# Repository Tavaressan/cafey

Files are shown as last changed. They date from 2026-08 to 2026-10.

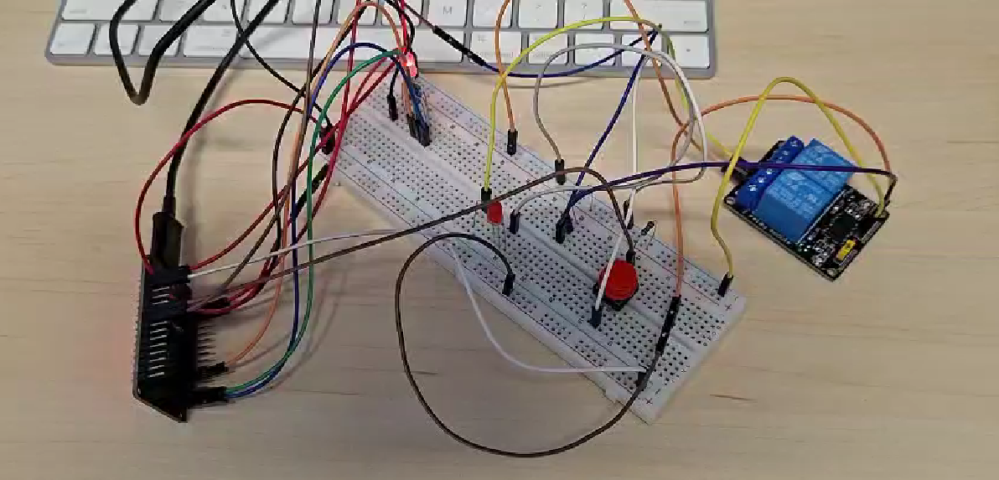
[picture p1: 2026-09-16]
docs/docs_artigo/imagens_artigo/screenshot_teste_bancada_prototipo_embarcado_cafey.png

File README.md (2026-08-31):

# Cafey — Cafeteira Conectada

Projeto Integrador do 6º semestre (Desenvolvimento de Software Multiplataforma, Fatec Itaquera).

Módulo IoT (Internet of Things — Internet das Coisas) externo, em formato de base de aço, que
transforma qualquer cafeteira de chave mecânica em aparelho conectado, sem modificação interna.
Um ESP32 aciona um relé que corta a fase da alimentação da cafeteira. Controle por app Kotlin
Multiplataforma (web/mobile/desktop), backend Kotlin + Spring Boot, PostgreSQL, MQTT (Message
Queuing Telemetry Transport) sobre AWS IoT Core.

## Estrutura

```
/
├── hardware/   KiCad — esquemático, PCB e bibliotecas do módulo eletrônico
├── firmware/   C++ / ESP-IDF — firmware do ESP32
├── backend/    Kotlin / Spring Boot — API e integração MQTT
├── apps/       Kotlin Multiplataforma — app web/mobile/desktop
└── docs/       Especificação e documentação acadêmica
```

## Abrindo o esquemático

Requer **KiCad 10.0.5** (ou outra versão 10.0.x) — a mesma versão maior usada para criar o
projeto. Abra `hardware/pi_dsm_26_2.kicad_pro`.

A biblioteca de símbolo de terceiros usada pelo ESP32 (`ESP32_30Pin`, DOIT ESP32 DevKit V1 de 30
pinos) está versionada em `hardware/libraries/esp32_30pin.kicad_sym` e registrada na tabela de
bibliotecas do projeto (`hardware/sym-lib-table`) com caminho relativo — não depende de nenhuma
biblioteca instalada fora do repositório.

## Aviso de segurança elétrica

O hardware envolve tensão de rede (127 V). A montagem exige validação por profissional de
elétrica antes do primeiro uso com carga real.

## Cronograma

Execução individual, oito semanas. Hardware e software avançam em paralelo, mas nunca no mesmo
dia: bancada e solda pedem bloco contínuo, código admite sessões curtas.

**Posição atual (31/08/2026):** Fase 1, esquemático elétrico validado. O gargalo do momento é a
compra dos componentes — ela bloqueia a bancada, o desenho mecânico e a validação elétrica ao
mesmo tempo.

### Fase 1 — Fundação (24/08 – 04/09)

| Estado | Entrega |
|---|---|
| ✅ | Especificação técnica v1.1 |
| ✅ | Seleção da cafeteira: Britânia CP30 Inox, 800 W, 127 V, chave KCD1-106 |
| ✅ | Decisões de hardware fechadas (alimentação, relé, LED, proteção, pinagem) |
| ✅ | Esquemático KiCad validado nó a nó contra a especificação |
| ✅ | Repositório e documentação de estado |
| ⬜ | Compra dos componentes |
| ⬜ | Conferência de bancada: serigrafia do DevKit, pinagem do módulo de relé, pernas do LED |
| ⬜ | Protótipo do relé em bancada acionado pelo ESP32 |
| ⬜ | Esqueleto do backend com autenticação |

### Fase 2 — Núcleo (07/09 – 25/09)

| Trilha | Entrega |
|---|---|
| Firmware | Estrutura de Active Objects sobre FreeRTOS; persistência em NVS (Non-Volatile Storage — armazenamento não volátil) |
| Firmware | MQTT sobre TLS (Transport Layer Security — segurança da camada de transporte) com certificado X.509; integração AWS IoT Core |
| Backend | API REST de dispositivos, comandos e agendamentos; consumo MQTT |
| Mobile | Operação básica: login, ligar, desligar, estado em tempo real |
| Estrutura | Desenho mecânico da chapa e solicitação de dobra à empresa |
| Artigo | Escrita incremental (ver trilha própria abaixo) |

### Fase 3 — Funcionalidade completa (28/09 – 09/10)

| Trilha | Entrega |
|---|---|
| Firmware | Agendamento local disparando por relógio sincronizado por NTP (Network Time Protocol — protocolo de tempo de rede) |
| Backend | Histórico de preparos, estatísticas, contador de descalcificação |
| Clientes | Web e desktop no nível essencial, reaproveitando composables |
| Estrutura | Montagem da base: fixação, aterramento, separação alta/baixa tensão |
| Segurança | Validação da montagem elétrica por profissional habilitado |

### Fase 4 — Fechamento (12/10 – 16/10)

| Trilha | Entrega |
|---|---|
| Testes | Ciclo completo com carga real; agendamento offline; queda de rede |
| Firmware | Fallback BLE (Bluetooth Low Energy — Bluetooth de baixa energia) e proxy BLE, se o cronograma permitir |
| Documentação | Documentação acadêmica e preparação para a banca |

## Estrutura física

A base é uma chapa de aço dobrada, produzida internamente na empresa. O caminho crítico passa
pela compra dos componentes: sem as dimensões reais das peças, o desenho não fecha.

| # | Atividade | Depende de |
|---|---|---|
| 1 | Levantar dimensões de ESP32, módulo de relé, HLK-PM01, tomada fêmea | Compras |
| 2 | Planificação da chapa: recortes de tomada, cabo, botão e LED | 1 |
| 3 | Definir separação física entre região de rede e região de baixa tensão | 2 |
| 4 | Resolver posicionamento da antena (janela plástica ou antena externa) | 2 |
| 5 | Prever fixação do terminal olhal de aterramento na chapa | 2 |
| 6 | Solicitar dobra à empresa | 2, 3, 4, 5 |
| 7 | Montagem: fiação de rede em bornes com tampa, fixação dos módulos | 6 |
| 8 | Validação elétrica por profissional habilitado | 7 |

O item 3 não é detalhe de acabamento: a especificação exige rede elétrica e eletrônica de baixa
tensão em lados opostos da caixa, sem cabos de alta e baixa tensão em paralelo. O item 4 existe
porque a estrutura metálica atenua Wi-Fi e BLE.

## Artigo — EnGeTec 2026

Submissão prevista para 20/09, dentro da Fase 2 — o período de maior carga técnica. Mitigação:
sessões fixas de escrita às terças, quintas e sábados, alimentadas pelas decisões já registradas
na especificação. O artigo descreve a proposta e resultados parciais; não depende do projeto
concluído.

**Confirmar a data no Teams** — a orientação da disciplina remete a ela, e a data acima vem da
especificação do projeto.

| Semana | Atividade |
|---|---|
| 31/08 – 06/09 | Cadastro no site do evento; levantamento bibliográfico |
| 31/08 – 06/09 | Definir recorte do artigo e estrutura das seções |
| 07/09 – 13/09 | Fundamentação teórica e método |
| 14/09 – 20/09 | Resultados parciais, conclusão, revisão de formatação |
| 20/09 | Submissão |
| a definir | Apresentação no evento (requisito para o certificado e para os anais) |

**Requisitos de submissão:**

- Template oficial do EnGeTec, sem qualquer alteração de formatação
- Mínimo de 10 artigos relacionados; referências em livros
- Não usar sites ou blogs como referência
- Título, resumo e palavras-chave em português, inglês e espanhol
- Resumo com no máximo 180 palavras
- Norma única em todo o texto: ABNT ou APA
- E-mail do professor orientador por último na lista de autores
- Declaração de uso (ou não uso) de ferramentas de IA ao final

## Marcos de aceitação

| Data | Critério |
|---|---|
| 04/09 | Relé aciona a carga por comando do ESP32; backend autentica ponta a ponta |
| 20/09 | Artigo submetido ao EnGeTec |
| 25/09 | Comando emitido no mobile chega à base via AWS IoT |
| 02/10 | Montagem elétrica validada por profissional |
| 09/10 | Agendamento dispara offline; histórico exibindo eventos reais |
| 16/10 | Projeto pronto para a banca |

## Ordem de cortes

Se o cronograma apertar, corta-se nesta ordem:

1. Fallback BLE e proxy BLE
2. Gráficos de estatística (mantendo o histórico em lista)
3. Compartilhamento de dispositivo com convidado
4. Cliente desktop
5. Recuperação de senha

**Nunca cortar:** agendamento offline, botão físico, aterramento e isolamento elétrico.

Ver [`STATUS.md`](STATUS.md) para o estado atual do projeto.

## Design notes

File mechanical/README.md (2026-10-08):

# mechanical — módulo físico (pedestal)

Modelo paramétrico do pedestal de `docs/status-modulo-fisico.md`.

**Impressão 3D (atual, issue #116):** ver a seção
[Variante para impressão 3D (FDM)](#variante-para-impressão-3d-fdm-issue-116)
abaixo — `build_peca1_3d.py` / `build_peca2_3d.py` e os scripts `*_3d.py`. A
seção seguinte, sobre chapa dobrada, fica preservada como histórico de decisão
(o modelo em chapa não é mais o alvo de fabricação, mas os scripts continuam
funcionando e não foram removidos).

## Chapa dobrada (histórico — substituída pela variante 3D acima)

- **Peça 1** — peça dobrada (tampo + 4 saias + 4 abas de fundo + 4 abas de canto).
- **Peça 2** — fundo plano removível (tampa por baixo).
- **Montagem** — as duas peças na posição de projeto.
- **Arranjo** — montagem + divisória + volumes de referência dos componentes
  (caixas envolventes **estimadas**, em `params/componentes.csv`).

## Abordagem

Sólidos `Part` paramétricos, 100% por script headless, dirigidos pelo Spreadsheet
`params`. Sem o addon SheetMetal: a planificação é analítica
(`bend deduction = 2·setback − BA`), auditável e independente do unfolder frágil.
O SheetMetal fica reservado para quando o revisor da empresa exigir árvore
sheet-metal nativa ou unfold validado pela ferramenta dele.

Parâmetros de processo (`espessura`, `raio_dobra`, `fator_k`, `material`) são
**placeholders arbitrados** — é a planilha `params` que o revisor corrige, e a
geometria depende dela por expressão.

## Coordenadas

Face superior do tampo em `Z = 0`; a peça desce para `Z < 0`. `X` ao longo de
`pegada_x`, `Y` ao longo de `pegada_y`. `Y = 0` é a saia frontal (baixa tensão),
`Y = pegada_y` a traseira (rede). `X = 0` é a lateral esquerda. As duas peças
compartilham este sistema, então a Peça 2 entra na montagem sem deslocamento.

## Scripts

```
freecadcmd mechanical/scripts/build_peca1.py     # build/peca1.FCStd
freecadcmd mechanical/scripts/unfold_peca1.py    # tabela de dobras -> Spreadsheet 'planificacao'
freecadcmd mechanical/scripts/check_peca1.py     # validação Peça 1
freecadcmd mechanical/scripts/export_step.py     # build/peca1.step
freecadcmd mechanical/scripts/build_peca2.py     # build/peca2.FCStd + peca2.step
freecadcmd mechanical/scripts/check_peca2.py     # validação Peça 2 + coincidência de furos
freecadcmd mechanical/scripts/build_montagem.py  # build/montagem.FCStd + montagem.step
freecadcmd mechanical/scripts/check_montagem.py  # validação de conjunto (pilha de parafuso, cobertura, elevação)
freecadcmd mechanical/scripts/build_arranjo.py   # build/arranjo.FCStd + arranjo.step (divisória + volumes de referência)
freecadcmd mechanical/scripts/check_arranjo.py   # valida faixas, altura livre, separação rede/baixa
freecadcmd mechanical/scripts/flatten_peca1.py   # build/peca1_plano.FCStd (contorno planificado)
freecadcmd mechanical/scripts/export_dxf.py      # build/peca1_plano.dxf + peca2_plano.dxf
```

Ordem: `build_peca1` → `build_peca2` → `build_montagem` → `check_montagem` →
`build_arranjo` → `check_arranjo`;  `flatten_peca1` → `export_dxf`. `freecadcmd` = `/Applications/FreeCAD.app/Contents/Resources/bin/freecadcmd`
(FreeCAD 1.1.3).

`_build.py` reúne o Spreadsheet e as primitivas; `_env.py` reúne paths, fórmulas
(BA, setback, segmentos do blank, furos de porca-rebite) e as descrições
(`DESCRIPTIONS`). Cada objeto do FCStd carrega `Label` + `Label2` (campo
"Descrição"); os objetos `notas_fabricacao` e `notas_furos` reúnem o que não é
geometria. **[`FUROS.md`](FUROS.md)** — catálogo do propósito de cada furo e
abertura, espelhado no `notas_furos` de cada FCStd.

## Entregáveis (`build/`, fora do versionamento)

| Arquivo | Conteúdo |
|---|---|
| `peca1.FCStd` / `peca1.step` | Peça 1, sólido paramétrico |
| `peca2.FCStd` / `peca2.step` | Peça 2, fundo plano |
| `montagem.FCStd` / `montagem.step` | Conjunto (snapshot; `check_montagem.py` valida interferência = 0, pilha de parafuso, cobertura das abas, elevação) |
| `arranjo.FCStd` / `arranjo.step` | Montagem + divisória + 13 volumes de referência; `check_arranjo.py` valida faixas, altura livre, separação rede/baixa |
| `peca1_plano.FCStd` | Contorno planificado da Peça 1 |
| `peca1_plano.dxf` | **Contorno externo** da Peça 1 (365,4 × 315,4 mm) — sem aberturas |
| `peca2_plano.dxf` | Peça 2 **completa** (contorno 260 × 210 + 8 furos M3 + 2 furos de cantoneira) |

## Peça 2 — fundo (tampa por baixo)

- Chapa plana rente à face externa das saias (260 × 210), **parafusada na face
  inferior das abas de retorno da Peça 1**. Sai por baixo para manutenção — um
  fundo apoiado por dentro sobre as abas viradas para dentro ficaria preso
  (vão livre entre as abas 233,6 × 183,6 < fundo). Face superior coplanar com a
  face inferior das abas; protrai `espessura_fundo` abaixo da borda das saias.
  Os pés montam nela.
- 8 furos de passagem M3 gerados pelas **mesmas fórmulas** das porcas-rebite da
  Peça 1 (`_env.porca_rebite_holes`); o parafuso entra por baixo e rosqueia na
  porca-rebite da aba. `check_peca2.py` confirma a coincidência.
- 2 furos para as cantoneiras da divisória, na linha `y = espessura + faixa_baixa`
  (policarbonato/acrílico, altura plena, entre a faixa de rede e a de baixa tensão).

## Arranjo interno (`arranjo.FCStd`)

`build_arranjo.py` monta Peça 1 + Peça 2 + a divisória + um volume de referência
por componente, lido de **`params/componentes.csv`**. Cada volume é uma **caixa
envolvente estimada** — o usuário confirma os tamanhos editando o CSV e rodando
de novo. Cada objeto carrega `Label2` com a origem da estimativa (datasheet do
HLK-PM01, dimensão de mercado, dado do documento…).

Layout: faixa da rede (127 V) na traseira, divisória de 3 mm, faixa de baixa
tensão (5 V) na frente. HLK-PM01 e módulo de relé do lado da rede com os
terminais de baixa tensão voltados para a divisória; travessia única de 5 fios
(`travessia_fios`) por um rasgo de passa-fio na divisória. ESP32 com o eixo longo
frente-fundo, antena atrás da `janela_rf`.

`check_arranjo.py` valida: envelope vertical, componente dentro das paredes, sem
penetrar a chapa, separação de faixa (rede ≥ 10 mm da divisória), só a travessia
cruza o plano da divisória, ESP32 alinhado com a janela de RF, e reporta
interferências entre volumes.

**Achado do 1º passe (tamanhos estimados):** a divisória a "altura plena" e os
componentes altos (`borne_rede` ~34 mm) deixam pouca folga sob o tampo — a
divisória (40 mm) fica a **2,6 mm** do tampo. Altura interna útil ~43,8 mm.
Confirmar as alturas reais e decidir a folga da divisória.

## Planificação e DXF — limites

O `peca1_plano.dxf` é **só o contorno** (mais alívios e abas de canto). As
aberturas por face **não entram**: a posição planificada de cada abertura depende
do fator K real da ferramenta da empresa (consultas 6 e 7 da lista de
verificação). O contorno serve para dimensionar a chapa bruta (~400 × 350 mm) e
como base para o revisor aplicar o unfold da ferramenta dele.

Aberturas, na referência da peça dobrada (do documento), para o desenho cotado:

| Face | Abertura | Posição |
|---|---|---|
| Frontal | Janela RF 40×28 | x=75, centro 22 mm abaixo do tampo |
| Frontal | LED Ø5 | x=150 |
| Frontal | Botão Ø12 | x=195 |
| Traseira | Prensa-cabo PG9 Ø15 | x=70 |
| Traseira | Tomada J1 45,5×23 | x=185 |
| Laterais | Rasgos 25×3 | 15 mm da borda inferior (4 na esq. + USB, 5 na dir.) |

## Estado / limitações

- **Sem raios de dobra** nos sólidos (arestas vivas). Cosméticos para o STEP; a
  linha neutra real está na planificação analítica.
- `usb_w`, `usb_h`: placeholders — medir o flange do conector (item 16).
- `espessura_fundo`: arbitrado; confirmar a chapa.
- Furos de canto e das cantoneiras em posições provisórias.
- Parafusos do fundo: cabeça panela (saliente ~2 mm no vão de ar). Sem escareado
  — chapa de 1,2 mm é fina para escarear M3; confirmar com a empresa se quiser flush.
- `montagem.FCStd` é snapshot (cópia de forma), não assembly vivo.

## Notas de fabricação (chapa)

- **Ordem de dobra:** abas do fundo primeiro, com a chapa plana; saias depois. A
  viradeira não alcança o interior de uma caixa de 45 × 260 mm.
- Alívio de canto de `raio_dobra + espessura` (~2,4 mm) no encontro das dobras.
- Porta-fusível em linha preso por abraçadeira — nenhum furo em chapa.
- Alumínio em inox forma par galvânico; parafuso/rebite de inox (consulta 9).

---

## Variante para impressão 3D (FDM) — issue #116

Reformulação da mecânica para impressão 3D no lugar de chapa dobrada. Mesma
pegada (260 × 210 mm), mesma **cavidade útil** (40,2 mm) e mesmo arranjo
interno (`params/componentes_3d.csv`). A **altura externa cresceu de 45 para
53 mm**: os 8 mm extras (`reforco_delta`) são uma banda de nervura sob o
tampo — o subconjunto interno (piso + componentes de `apoio=fundo` + divisória)
desceu junto, translação rígida, sem novo arranjo. O que muda:

- **Peça 1 vira um sólido único** (tampo + 4 paredes + flange de fixação
  contínua) em vez de 8 dobras + 4 abas de canto — os 4 cantos já nascem
  fechados, sem fator K, sem linha neutra, sem planificação.
- **Parede 2,4 mm** (3 perímetros de bico 0,4 mm), contra 1,2 mm da chapa —
  mínimo prático para uma parede que é estrutura primária em FDM.
- **Reforço estrutural sob o tampo** (audit da carga de 3 kg): 4 colunas de
  canto tampo→fundo + nervura perimetral + nervura transversal na linha da
  divisória. Tudo paramétrico (`coluna_qtd`, `nervura_transversal`,
  `nervura_h`). Ver "Reforço estrutural" abaixo.
- **Fixação Peça 1 / Peça 2 por insert térmico rosqueado M3** (fundido a
  quente em 8 bosses da flange, `boss_d` = 9 mm, furo do insert `insert_furo`
  = 4,0 mm, profundidade `insert_prof` = 6 mm), no lugar da porca-rebite de
  chapa. O parafuso da Peça 2 continua entrando por baixo.
- **STL exportável** (`export_stl.py`), novo requisito da issue.
- Todas as aberturas do catálogo (`FUROS.md`) recriadas 1:1 na nova geometria.

### Scripts

```
freecadcmd mechanical/scripts/build_peca1_3d.py     # build/peca1_3d.FCStd
freecadcmd mechanical/scripts/check_peca1_3d.py     # validação Peça 1 (geometria, margens, flecha do tampo)
freecadcmd mechanical/scripts/export_step_3d.py     # build/peca1_3d.step
freecadcmd mechanical/scripts/build_peca2_3d.py     # build/peca2_3d.FCStd + peca2_3d.step
freecadcmd mechanical/scripts/check_peca2_3d.py     # validação Peça 2 + coincidência dos furos com os inserts
freecadcmd mechanical/scripts/check_montagem_3d.py  # validação de conjunto (sem build_montagem_3d.py: confere as duas Shapes direto)
freecadcmd mechanical/scripts/build_arranjo_3d.py   # build/arranjo_3d.FCStd + arranjo_3d.step
freecadcmd mechanical/scripts/check_arranjo_3d.py   # valida faixas, altura livre, separação rede/baixa, sem colisão com os bosses
freecadcmd mechanical/scripts/export_stl.py         # build/peca1_3d.stl + peca2_3d.stl (Peça 1 e Peça 2)
```

Ordem: `build_peca1_3d` → `build_peca2_3d` → `check_peca1_3d` → `check_peca2_3d`
→ `check_montagem_3d` → `build_arranjo_3d` → `check_arranjo_3d` →
`export_step_3d` / `export_stl`.

`_env3d.py` é o equivalente de `_env.py` para esta variante: paths de saída
(`peca1_3d.*`, `peca2_3d.*`, `arranjo_3d.*`), `DESCRIPTIONS`/notas de
fabricação, `insert_holes()` (posição dos 8 bosses/insertes, mesmo layout dos
antigos `porca_rebite_holes()`), `coluna_positions()` / `pe_positions()` /
`y_nervura_transversal()` (geometria do reforço) e `deflexao_tampo_mm(g,
com_reforco=)` — flecha de longo prazo do tampo (elástica × `fator_fluencia`),
placa ret. simpl. apoiada (Roark). `_build.py` (helpers `box`/`cyl`) é
reaproveitado sem mudança.

### Parâmetros (`params/parametros_3d.csv`)

Cópia de `parametros.csv` sem os campos de dobra (`raio_dobra`, `fator_k`,
`recuo_aba`, `alivio_canto`), com `espessura` renomeado para `parede` (2,4 mm)
e os novos parâmetros de fixação: `boss_d`, `insert_furo`, `insert_prof`,
`furo_passagem`. `aba_fundo` sobe de 12 para 14 mm (a flange também aloja o
boss do insert, Ø 9 mm). Adicionados no audit da carga de 3 kg: `altura_externa`
45→53, `reforco_delta`, `nervura_h`/`nervura_w`/`nervura_transversal`,
`coluna_qtd`/`coluna_lado`, `travessia_folga`, `pe_d`/`pe_inset`,
`carga_operacao` (3,0 kgf), `fator_fluencia` (4,0), `folga_comp_reforco`.

### Reforço estrutural sob o tampo (audit da carga de 3 kg)

O modelo inicial do #116 só validava a flecha **elástica** do tampo sob
2,9 kg e passava raspando (0,57 mm vs. limite `L/300` = 0,70 mm). O audit
apontou dois furos: (1) faltava a **fluência** — PETG sob carga contínua +
calor irradiado deforma 3–4× a flecha elástica ao longo de meses; (2) o
pedido é **3 kg**, não 2,9. Com `fator_fluencia = 4` e `carga_operacao = 3,0`,
o tampo **liso** dá flecha de longo prazo ≈ **2,4 mm** — estoura o limite.

Reforço adicionado, todo paramétrico em `parametros_3d.csv`:

| Elemento | Param | Função |
|---|---|---|
| 4 colunas de canto (tampo → plano do fundo) | `coluna_qtd` (4), `coluna_lado` (12) | Caminho de carga vertical direto aos pés; travam o corpo contra racking |
| Nervura perimetral sob o tampo | `nervura_h` (6), `nervura_w` (3) | Enrijece a borda do tampo e o topo das paredes |
| Nervura transversal (linha da divisória) | `nervura_transversal` (1) | Divide o vão do tampo em 2 painéis → vão efetivo 210 → **118 mm**, flecha ÷ ~10 |
| Assentos de pé coaxiais com as colunas | `pe_d` (15) na Peça 2 | Fecham o caminho tampo → coluna → fundo → pé → bancada |

Resultado (`check_peca1_3d.py`): flecha de longo prazo **com** reforço ≈
**0,24 mm** < `L/300` = 0,70 mm. A peça imprime de cabeça para baixo (tampo
na mesa) — nervuras e colunas crescem a partir do tampo, **sem suporte**.

`coluna_qtd = 0` e `nervura_transversal = 0` voltam ao modelo do #118 (nesse
caso rebaixar `altura_externa` de 53 para 45). **Estimativa analítica, não
FEA nem ensaio** — o ensaio de bancada com o protótipo impresso e a carga
real por semanas (fluência) é o que confirma.

### Massa e resistência mecânica — decisões e premissas

- **Material assumido: PETG** (`_env3d.MATERIAL_TXT`), não validado por
  ensaio — ver `docs/status-modulo-fisico.md` para a justificativa e a
  ressalva. Densidade usada apenas para uma estimativa de massa em **sólido
  cheio** (limite superior; o infill parcial do fatiador reduz a massa real).
- **Flecha do tampo sob carga de operação:** `_env3d.deflexao_tampo_mm(g,
  com_reforco=)` — flecha **de longo prazo** = elástica (placa ret. simpl.
  apoiada, Roark) × `fator_fluencia`. `check_peca1_3d.py` reporta o valor
  **sem** reforço (≈ 2,4 mm, referência do audit) e valida o valor **com**
  reforço (≈ 0,24 mm) contra `L/300` do menor vão. **Inferência de
  engenharia, não ensaio** — item 8/10 da lista de verificação.
- **Sem fillet nos cantos verticais** nesta primeira versão — decisão
  consciente (YAGNI): nenhum requisito de resistência levantado pela issue
  exige isso agora; fica como melhoria futura se o ensaio de bancada indicar
  necessidade.

### Arranjo interno (`arranjo_3d.FCStd`)

Mesmos 14 componentes de `componentes.csv`, mesma separação rede/baixa
tensão. Ajustes em `componentes_3d.csv`:
- Componentes de `apoio=fundo` em standoffs acima do topo dos bosses de
  insert (que ficam mais altos que a flange de 2,4 mm).
- Todo o subconjunto interno referenciado ao piso (`apoio` ∈ fundo /
  divisória / abraçadeira / livre / fios) **desceu 8 mm** (`reforco_delta`)
  com o crescimento de `altura_externa` 45→53 — abre a banda de nervura sob
  o tampo sem mexer nas folgas internas (standoff 6 mm, divisória→piso
  2,4 mm são as mesmas do #118).
- Divisória 2,4 mm mais estreita de cada lado (255,2 × 3 × 40) e agora com
  topo em `z=-10,6` — 2,2 mm abaixo da nervura transversal.

`check_arranjo_3d.py` confirma: zero interferência entre os 14 volumes, zero
penetração na peça impressa, **8,1 mm** de folga sob o tampo (a banda de
nervura); e `check_peca1_3d.py` valida que nenhuma nervura/coluna colide com
os volumes internos (folga mínima 2,1 mm ≥ `folga_comp_reforco`).

**Modelos visuais.** Para 11 dos 13 componentes, `build_arranjo_3d.py` coloca
um modelo STEP/IGES de `models/` (tabela `MODELS`) sobre o volume de referência
e oculta a caixa. O modelo é só representação: a validação continua sobre as
caixas, e o build imprime quanto cada modelo passa do seu volume. Origem,
licença e divergências modelo × peça real estão em
[`models/FONTES.md`](models/FONTES.md). O `models/esp32-devkit-v1.step` é
montado por `make_esp32_devkit_v1.py` a partir da biblioteca 3D do KiCad. O `freecadcmd` não lê as cores dos
modelos; para gerar o FCStd e o STEP coloridos, rode o mesmo script pela GUI
do FreeCAD sem janela:

```
QT_QPA_PLATFORM=offscreen FreeCAD mechanical/scripts/build_arranjo_3d.py
```

### Entregáveis (`build/`, fora do versionamento)

| Arquivo | Conteúdo |
|---|---|
| `peca1_3d.FCStd` / `.step` / `.stl` | Peça 1 impressa (sólido único) |
| `peca2_3d.FCStd` / `.step` / `.stl` | Peça 2, fundo plano impresso |
| `arranjo_3d.FCStd` / `.step` | Peça 1 + Peça 2 + divisória + 13 volumes de referência (11 ocultos sob modelos visuais; o STEP leva só os visíveis, sem as peças) |

### Estado / limitações

- `usb_w`, `usb_h`: placeholders — medir o flange do conector (item 16, doc).
- `boss_d`/`insert_furo`/`insert_prof`: valores nominais de insert térmico
  M3x5,7 comum no mercado (ex. Ruthex/Boyard) — confirmar contra o insert
  realmente comprado antes de imprimir o protótipo.
- Sem fillet nos cantos verticais (ver acima).
- **`fator_fluencia` (4,0) é arbitrado** — faixa típica de termoplástico
  carregado, mas o valor real do PETG impresso sob a temperatura da base da
  cafeteira só sai de um ensaio de fluência de semanas (item 8/10). Se o
  ensaio der pior, subir `nervura_h` ou `parede`.
- **Flange na base imprime como ponte** de `aba_fundo` (14 mm) para dentro,
  sem chanfro 45° — aceitável para PETG a 14 mm, mas confirmar no protótipo;
  chanfro fica como melhoria paramétrica se reprovar.
- `pe_d`/`pe_inset`: assento de pé é só um rebaixo de localização (1,2 mm) —
  o pé em si (EPDM/silicone adesivo, `pe_altura` 10 mm) é externo.
- `arranjo_3d.FCStd` é snapshot, não assembly vivo (mesma limitação da
  versão em chapa).

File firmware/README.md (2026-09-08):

# Firmware — ESP32 (ESP-IDF C++17)

Firmware do módulo IoT da cafeteira Cafey desenvolvido em **C++17** sobre o framework oficial **ESP-IDF** (com FreeRTOS).

Fatia atual: **I/O local, Driver do Relé (com proteção anti-glitch no boot) e módulo Wi-Fi (conexão, reconexão automática e provisionamento de credenciais — UC-04)**. Botão alterna o relé; LED RGB indica o estado.

## Pinagem Definida

| Sinal | GPIO | Configuração Elétrica | Observação |
|---|---|---|---|
| Relé (IN) | 26 | Gatilho de nível BAIXO — módulo HL-52S (LOW = ligado); R1 10 kΩ pull-up externo | O driver força nível ALTO antes de inicializar para impedir pulso espúrio no boot |
| Botão | 27 | R2 10 kΩ pull-up externo + C3 100 nF debounce RC | Solto = 1, pressionado = 0 (borda de descida = clique) |
| LED vermelho | 21 | R3 220 Ω (Cátodo comum) | Aceso = cafeteira desligada |
| LED verde | 22 | R4 100 Ω (Cátodo comum) | Aceso = cafeteira ligada |
| LED azul | 23 | R5 100 Ω (Cátodo comum) | Aceso durante o boot |

## Estrutura do Projeto

```
firmware/
├── CMakeLists.txt         # Configuração raiz CMake (C++17, IDF project)
├── partitions.csv         # Tabela de partições customizada (nvs, phy_init, factory, storage)
├── sdkconfig.defaults     # Configurações do ESP-IDF (C++, partições, FreeRTOS 1000Hz)
├── wokwi.toml             # Configuração do simulador Wokwi
├── diagram.json           # Esquemático de simulação Wokwi
├── main/
│   ├── CMakeLists.txt     # Registro do componente main e fontes C++
│   ├── main.cpp           # Ponto de entrada app_main (extern "C") e namespace cafey
│   ├── drivers/
│   │   ├── relay.hpp      # Header do driver de relé C++ com RAII e anti-glitch
│   │   └── relay.cpp      # Implementação do driver cafey::drivers::Relay
│   └── core/              # Estruturas e active objects centrais
│       ├── reconnect_policy.hpp/.cpp    # Backoff exponencial puro (cafey::core::ReconnectPolicy)
│       ├── wifi_credentials.hpp/.cpp    # Persistência NVS de SSID/senha (cafey::core::WifiCredentialsStore)
│       └── wifi_manager.hpp/.cpp        # Orquestração Wi-Fi STA via esp_wifi/esp_event (cafey::core::WifiManager)
└── test/
    ├── CMakeLists.txt          # Suíte de testes unitários nativos para host (C++17 / CTest)
    ├── mock_esp_gpio.hpp       # Mock da camada GPIO do ESP-IDF para testes sem hardware
    ├── mock_esp_nvs.hpp        # Mock da camada NVS do ESP-IDF para testes sem hardware
    ├── test_relay.cpp          # Testes unitários do driver do relé (TDD)
    ├── test_reconnect_policy.cpp    # Testes unitários do backoff de reconexão (TDD)
    └── test_wifi_credentials.cpp    # Testes unitários da persistência de credenciais (TDD)
```

## Driver do Relé (`cafey::drivers::Relay`)

- **Classe Orientada a Objetos**: RAII garantindo desligamento seguro no destrutor.
- **Proteção Anti-Glitch**: Força o pino em nível lógico `HIGH` (active-low OFF) antes e imediatamente após a configuração de saída do GPIO, atuando em conjunto com o resistor `R1` (10k pull-up) externo.
- **Métodos**: `init()`, `set(bool on)`, `turn_on()`, `turn_off()`, `toggle()`, `is_on()`, `is_initialized()`, `get_pin()`.
- **Semântica Move**: Proteção contra duplicação de posse do hardware físico via exclusão de cópia e suporte a movimentação (`move`).

## Módulo Wi-Fi (`cafey::core::WifiManager`) — UC-04

- **Conexão STA**: inicializa `esp_wifi` em modo estação sobre o event loop padrão do ESP-IDF (`esp_event`).
- **Reconexão automática**: ao receber `WIFI_EVENT_STA_DISCONNECTED`, agenda uma nova tentativa via `esp_timer` (sem bloquear a task do event loop) com backoff exponencial calculado por `ReconnectPolicy` (1 s → dobra a cada falha → teto de 60 s); o contador de tentativas e o atraso são resetados ao obter IP (`IP_EVENT_STA_GOT_IP`).
- **Provisionamento de credenciais**: `WifiManager::provision(ssid, password)` grava o SSID/senha via `WifiCredentialsStore` (namespace NVS `cafey_wifi`) e conecta imediatamente; no boot, se já houver credenciais gravadas, conecta direto — caso contrário, permanece em `WifiState::NOT_PROVISIONED` aguardando o app/BLE provisionar (a exposição via BLE é escopo de FW-17).
- `ReconnectPolicy` e `WifiCredentialsStore` são unidades puras/isoladas do hardware, com testes unitários de host (`test_reconnect_policy.cpp`, `test_wifi_credentials.cpp`); `WifiManager` em si integra diretamente com `esp_wifi`/`esp_event`/`esp_timer` e é validado pela build real do ESP-IDF (CI).

## Executar Testes Unitários Nativos (Host)

Os testes unitários (driver do relé, backoff de reconexão e persistência de credenciais Wi-Fi) podem ser compilados e executados em qualquer máquina de desenvolvimento (macOS / Linux) sem necessidade da toolchain física do ESP-IDF instalada:

```sh
cd firmware/test
mkdir -p build && cd build
cmake ..
make
ctest --output-on-failure
```

## Simulação no Wokwi (wokwi.com)

1. Abra o Wokwi para ESP32 ESP-IDF (<https://wokwi.com/projects/new/esp-idf-esp32>).
2. Adicione os fontes de `firmware/` (`main.cpp`, `drivers/relay.hpp`, `drivers/relay.cpp`).
3. Cole o conteúdo de `diagram.json` e `wokwi.toml`.
4. Clique em **Run**. O log serial reportará o boot com LED azul e ao clicar no botão `SW1`, o relé e o LED alternam o estado.

### Simulação headless via `wokwi-cli` (CI local / validação sem hardware)

```sh
curl -L https://wokwi.com/ci/install.sh | sh   # instala em ~/bin/wokwi-cli
export WOKWI_CLI_TOKEN=<seu-token>             # gerado em https://wokwi.com/dashboard/ci
cd firmware
. ~/.espressif/v6.1/esp-idf/export.sh && idf.py build   # gera build/cafey_firmware.elf
wokwi-cli --serial-log-file /tmp/serial.log .            # lê wokwi.toml automaticamente
```

**Gotcha crítico:** `diagram.json` precisa conectar explicitamente os pinos TX0/RX0 do ESP32 ao
part virtual `$serialMonitor`, senão o `wokwi-cli` conecta na API normalmente e a simulação roda
(inclusive o firmware de verdade), mas **nenhum byte de serial chega ao CLI** — nem o banner de
boot do ROM, que independe do firmware. É silencioso: sem erro, sem timeout diferenciado, só
`--serial-log-file` vazio. As duas conexões que resolvem:
```json
[ "esp:TX0", "$serialMonitor:RX", "", [] ],
[ "esp:RX0", "$serialMonitor:TX", "", [] ]
```
Diagramas antigos/copiados do editor web às vezes não têm essa conexão (o editor web injeta um
monitor serial implícito que o `wokwi-cli` headless não replica). Rode `wokwi-cli lint .` para
pegar problemas de fiação — mas o lint não detecta a ausência do `$serialMonitor` (não é erro de
fiação, é ausência de conexão opcional do ponto de vista do simulador).

## Compilação Local com ESP-IDF (≥ 5.x)

```sh
. $IDF_PATH/export.sh
idf.py set-target esp32
idf.py build
idf.py -p <porta> flash monitor
```

### Evitando "idf.py: command not found"

- **`. export.sh` não persiste entre comandos de shell separados.** Cada terminal/execução novos
  precisa dar `source` de novo — não é algo que se "instala" uma vez. Se for automatizar (script,
  CI local, agente), o `source` e o `idf.py` têm que estar na **mesma** invocação de shell:
  ```sh
  . "$HOME/.espressif/v6.1/esp-idf/export.sh" && idf.py build
  ```
- **Instalação incompleta é a causa mais comum.** O toolchain (compiladores, cmake, ninja) pode já
  estar baixado em `~/.espressif/<versão>/` sem o venv Python ter sido criado — nesse caso
  `export.sh` falha com `ESP-IDF Python virtual environment ... not found`. Reinstale com:
  ```sh
  bash ~/.espressif/<versão>/esp-idf/install.sh esp32
  ```
- **A build real (`idf.py build`) é a única que valida o firmware de verdade.** A suíte de host
  (seção acima) cobre lógica pura via mocks, mas não pega problemas específicos do ESP-IDF (headers
  ausentes, `REQUIRES` de componente faltando, mudança de struct entre versões) — só o CI (Docker
  `espressif/idf:v5.3`) ou uma instalação local do ESP-IDF pegam isso. Se o Docker também estiver
  indisponível localmente (`docker info` falhando), a build real via `idf.py` é o único jeito de
  validar antes do CI.
- **Divergência de versão local vs. CI é uma fonte real de falso-negativo/falso-positivo.** O CI
  fixa `espressif/idf:v5.3`; uma instalação local em outra versão (ex. v6.1) pode expor mudanças de
  API/struct que não existem no v5.3 (e vice-versa). Ao investigar um erro de build que só aparece
  local ou só no CI, confira a versão primeiro (`idf.py --version`) antes de assumir que é bug de
  código.

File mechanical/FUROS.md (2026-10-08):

# Catálogo de furos e aberturas — módulo físico

**Nota (issue #116 — impressão 3D):** este catálogo descreve a versão em
chapa dobrada (`build_peca1.py`/`build_peca2.py`, histórico). A versão atual,
impressa em FDM (`build_peca1_3d.py`/`build_peca2_3d.py`), recria **as mesmas
aberturas, nas mesmas coordenadas (x, y, z)** — só os nomes de objeto mudam
(`saia_*` → `parede_*`; `fix_*`/`pr_*` → `boss_*`/`insert_*`, que agora
resolvem a fixação Peça1/Peça2 por insert térmico em vez de porca-rebite; não
há mais furo de canto porque a peça impressa já nasce fechada nos 4 cantos).
Ver `_env3d.NOTAS_FUROS_P1`/`NOTAS_FUROS_P2` (texto embutido no FCStd) e a
seção "Variante para impressão 3D" de `mechanical/README.md` para o
detalhamento da fixação nova. As tabelas abaixo continuam válidas para as
posições x/y das aberturas de face e dos rasgos — só a peça de fixação dos
cantos deixou de existir.

Propósito de cada furo/abertura dos modelos. Coordenadas no sistema das peças
(face superior do tampo em `Z = 0`; `X` ao longo de `pegada_x`; `Y = 0` = saia
frontal / baixa tensão; `Y = pegada_y` = saia traseira / rede; `X = 0` = lateral
esquerda). Espelhado nos FCStd pelos objetos `notas_furos` e pelo campo
**Descrição** (`Label2`) de cada objeto.

Valores são dos parâmetros arbitrados atuais — o revisor da empresa ajusta na
planilha `params` e a geometria acompanha por expressão.

---

## Peça 1 — aberturas de face

Centro a 22 mm abaixo do tampo (`abertura_centro_z`).

| Objeto | Forma | Face | Centro (x, y, z) | Propósito |
|---|---|---|---|---|
| `janela_rf` | retângulo 40 × 28 | frontal | (75, 0, −22) | **Saída de rádio.** Deixa a antena Wi-Fi do ESP32 (encostada por dentro, ~5 mm, sem metal na frente) enxergar para fora. Não é acesso a componente. Dimensão cobre a antena PCB do DevKit V1 com margem. Valida no ensaio 11 (atenuação de Wi-Fi). |
| `furo_led` | Ø5 | frontal | (150, 0, −22) | **Sinalização.** Passagem do LED RGB de status, preso na parede pelo aro (M2) e ligado à placa auxiliar da faixa de baixa tensão por um rabicho de 4 fios (R, G, B, cátodo) de ~10 cm com conector — ver `docs/status-modulo-fisico.md`, "LED de status". Ø nominal — conferir contra o LED/porta-LED real (item 5). |
| `furo_botao` | Ø16 | frontal | (195, 0, −22) | **Comando.** Passagem do botão de painel metálico momentâneo NA de 16 mm (revisão 08/09/2026; era Ø12). Ø nominal — conferir contra o botão real (M1 da lista de compras). Ligado à placa auxiliar por rabicho de 2 fios com JST-XH — ver `docs/status-modulo-fisico.md`, "Botão". |
| `prensa_cabo` | Ø15 | traseira | (70, 210, −22) | **Entrada de energia do módulo** (rede 127 V vinda da parede). Recebe o prensa-cabo PG9 — alívio de tração normalizado que a inspeção elétrica procura. Escolhido em vez de passa-fio ou C14: menor recorte numa saia que já perdeu a tomada J1. Faixa de aperto 4–8 mm nominal vs cabo real (item 14). |
| `tomada_j1` | retângulo 45,5 × 23 | traseira | (185, 210, −22) | **Saída de energia.** Recorte do módulo de tomada 2P+T (NBR 14136) onde a **cafeteira** é plugada; o módulo comuta essa tomada pelo relé. Girado 90°: 45 mm de recorte numa saia de 45 mm não deixaria material; girado sobram ~10 mm acima e abaixo. Travamento das garras em chapa 1,2 mm a verificar (item 1). |
| `recorte_usb` | retângulo ~16 × 9 | lateral esq. | (0, 37,5, −22) | **Gravação / debug.** Passagem do conector USB de painel, ligado ao micro-USB do ESP32 por cabo de painel. Esse cabo desacopla a posição do conector da da placa — no DevKit V1 antena e micro-USB ficam em extremidades opostas, então sem ele "USB acessível" e "Wi-Fi decente" seriam exclusivos. Dimensão **placeholder** — medir o flange real (item 16; cabo M8 da lista de compras). Ligação e percurso: `docs/status-modulo-fisico.md`, "USB de painel". |

## Peça 1 — rasgos de ventilação

**Função térmica.** 25 × 3 mm, centro a 15 mm da borda inferior da saia
(`rasgo_altura`). Com os pés, impedem a caixa de virar forno selado e deixam o
fundo trocar calor com o vão de ar — a fonte de calor está em cima e o topo é
fechado, então não há efeito chaminé. **3 mm bloqueia dedo, não bloqueia arame
fino → bornes com tampa na faixa de rede são obrigatórios.**

| Objeto | Face | Centro y | Observação |
|---|---|---|---|
| `rasgo_e_1` | lateral esq. | 71,25 | |
| `rasgo_e_2` | lateral esq. | 105 | |
| `rasgo_e_3` | lateral esq. | 138,75 | |
| `rasgo_e_4` | lateral esq. | 172,5 | |
| `rasgo_d_0` | lateral dir. | 37,5 | posição que na esquerda é do `recorte_usb` |
| `rasgo_d_1..4` | lateral dir. | 71,25 / 105 / 138,75 / 172,5 | |

A esquerda tem 4 (o USB ocupa a 5ª posição da grade); a direita tem 5. A
assimetria é proposital — não corrigir.

## Peça 1 — furação

| Objeto (padrão) | Ø / eixo | Qtd | Propósito |
|---|---|---|---|
| `fix_<e\|d><f\|t>_<lo\|hi>` | Ø3,2 (M3) / eixo X | 8 (2 por canto) | **Montagem da caixa.** Prende a aba de canto (que sai da saia frontal/traseira) contra a face interna da lateral, fechando o corpo. Parafuso M3 inox (premissa) ou rebite (alternativa paramétrica) — alumínio em inox forma par galvânico e aqui derrame de café é rotina (item 9). Alturas a 1/3 e 2/3 da saia — provisórias. |
| `pr_<f\|t\|e\|d><a\|b>` | Ø~4,5 / eixo Z | 8 (2 por aba) | **Fixação do fundo, lado Peça 1.** Recebe a porca-rebite M3 nas abas de retorno, onde os parafusos da Peça 2 entram. Ø de furo da porca-rebite para chapa 1,2 mm: ~4,5 mm nominal — confirmar item 17. |

Centros `fix_*`: x ≈ 1,2 / 258,8 · y ≈ 11,2 / 198,8 · z ≈ −30,4 (lo) / −15,8 (hi).
Centros `pr_*`: gerados por `_env.porca_rebite_holes` — x ∈ {7,2 · 86,7 · 173,3 ·
252,8}, y ∈ {7,2 · 70 · 140 · 202,8}, z ≈ −44,4.

## Peça 1 — o que **não** tem furo

- **Tampo:** nenhuma abertura (regra de derrame).
- **Fusível:** porta-fusível 5×20 mm **em linha** (com rabicho), corpo fechado,
  preso por abraçadeira. Nenhum furo na parede — troca abrindo o fundo.
  Confirmado na revisão de 08/09/2026 (item E12 da lista de compras): **não**
  usar porta-fusível de painel. F1 = 10 A T, protege a carga.
- **Travessia de 5 fios** (+5 V/GND do HLK-PM01 + VCC/GND/IN do relé): rasgo com
  passa-fio na **divisória** de policarbonato, perpendicular a ela — não na
  chapa. A divisória não está modelada.
- `relief_*`: alívios de canto (entalhe no encontro das dobras), não furos.

---

## Peça 2 — fundo plano (tampa por baixo)

Chapa plana rente à face externa das saias (260 × 210), **parafusada na face
inferior das abas de retorno da Peça 1**. Sai por baixo para manutenção — um
fundo apoiado por dentro sobre as abas viradas para dentro ficaria preso (o vão
livre entre as bordas internas das abas é 233,6 × 183,6, menor que o fundo).
Face superior coplanar com a face inferior das abas (`Z = −altura_externa`);
protrai `espessura_fundo` (1,2 mm) abaixo da borda das saias. Os pés montam nela.

| Objeto (padrão) | Ø / eixo | Qtd | Propósito |
|---|---|---|---|
| `fundo_furo_1..8` | Ø3,2 (M3) / eixo Z | 8 | **Fixação do fundo, lado Peça 2.** Furo de **passagem**: o parafuso entra por baixo e rosqueia na porca-rebite `pr_*` da aba da Peça 1. Coincidem com os `pr_*` — mesmas fórmulas em `_env.porca_rebite_holes`, `check_peca2.py` confirma. Cabeça panela no vão de ar entre os pés. Abrir o fundo = trocar o fusível e acessar todo o interior. |
| `cant_furo_1..2` | Ø3,2 (M3) / eixo Z | 2 | **Separação elétrica.** Fixam as cantoneiras que seguram a divisória (policarbonato ou acrílico, altura plena) na linha `y = espessura + faixa_baixa` ≈ 85, entre a faixa de rede (127 V, traseira) e a de baixa tensão (5 V, frontal). Nenhum condutor de rede a menos de 10 mm da divisória — valida com o eletricista (marco 02/10). |

Centros `fundo_furo_*` = mesmos (x, y) dos `pr_*`. Centros `cant_furo_*`:
(65, 85,2) e (195, 85,2).

---

## Variante impressa (FDM) — fixação Peça 1 / Peça 2

Substitui `fix_*` (parafuso de canto — não existe mais, peça já nasce
fechada) e `pr_*`/`fundo_furo_*` (porca-rebite) da chapa. Mesmas 8 posições
(x, y) — geradas por `_env3d.insert_holes`, layout idêntico ao antigo
`_env.porca_rebite_holes`.

| Objeto (padrão) | Ø / eixo | Qtd | Propósito |
|---|---|---|---|
| `boss_<f\|t\|e\|d><a\|b>` | Ø9 (boss_d) / eixo Z | 8 | Reforço cilíndrico na flange, altura `insert_prof` (6 mm) — mais alto que a flange (2,4 mm) para caber o insert. Motivo do ajuste de z dos componentes `apoio=fundo` em `componentes_3d.csv` (sobem para standoff acima do boss). |
| `insert_<f\|t\|e\|d><a\|b>` | Ø4,0 (insert_furo) / eixo Z | 8 | Furo cego pela face inferior, profundidade 6 mm. Aloja o insert térmico M3×5,7 fundido a quente após a impressão. |
| `fundo_furo_1..8` (Peça 2) | Ø3,4 (furo_passagem) / eixo Z | 8 | Folga do parafuso M3 na Peça 2 — mesma lógica de montagem da chapa (parafuso entra por baixo, rosqueia no insert). |

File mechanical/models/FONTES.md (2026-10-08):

# Modelos visuais — origem, licença e divergências

Modelos usados por `scripts/build_arranjo_3d.py` (tabela `MODELS`) no lugar das
caixas de `params/componentes_3d.csv`. São **representação visual**: a validação
(`check_arranjo_3d.py`) continua sobre as caixas, que ficam ocultas no FCStd.

| Arquivo | Componente | Origem | Licença |
|---|---|---|---|
| `esp32-devkit-v1.step` | `esp32` | Gerado por `scripts/make_esp32_devkit_v1.py` com peças da biblioteca 3D do KiCad 10.0 (WROOM-32, 2× barra 1×15, micro-USB Molex 47346, 2× PTS810, SOT-223, QFN-28); placa, furos e fileiras pelo footprint `ESP32_30pin` de [syauqibilfaqih/ESP32-DevKit-V1-DOIT](https://github.com/syauqibilfaqih/ESP32-DevKit-V1-DOIT) @ `80365a4` (MIT) | Idem KiCad |
| `modulo-rele-v3.step` | `modulo_rele` | GrabCAD, `5v-relay-module-v3-0-1.snapshot.6.zip` | Termos do GrabCAD |
| `barramento-terra-lukma-6p.iges` | `terra_j3` | GrabCAD, `barra-de-bornes-terra-1.snapshot.6.zip` (`Barramento Terra LUKMA.iges`) | Termos do GrabCAD |
| `porta-fusivel-inline.step` | `porta_fusivel` | GrabCAD, `inline-fuse-holder-1.snapshot.2.zip` (autor no cabeçalho: jvalderrama) | Termos do GrabCAD |
| `tomada-tpa2-3-e3f.igs` | `tomada_j1_corpo` | GrabCAD, `tomada-2p-t-10-a-nbr-14136-referencia-tpa2-3-e3f-…-black-1.snapshot.2.zip` | Termos do GrabCAD |
| `placa-ilhada-60x40.step` | `placa_aux` | GrabCAD, `prototype-pcb-1.snapshot.1.zip` (`STEP/60mm x 40mm.step`) | Termos do GrabCAD |
| `PG9 Gland.step` | `prensa_cabo_corpo` | Baixado pela equipe como modelo do prensa-cabo PG9 (peça sem modelo na primeira busca); site de origem não anotado (cabeçalho: exportado do FreeCAD, 2023-01-13) | Desconhecida |
| `hlk-pmxx.step` | `hlk_pm01` | Biblioteca 3D do KiCad 10.0, `Converter_ACDC.3dshapes/Converter_ACDC_Hi-Link_HLK-PMxx.step` | [CC-BY-SA 4.0 com exceção para designs e arquivos gerados](https://gitlab.com/kicad/libraries/kicad-packages3D/-/blob/master/LICENSE.md) |
| `led-5mm-rgb.step` | `led_rgb` | Biblioteca 3D do KiCad 10.0, `LED_THT.3dshapes/LED_D5.0mm-4_RGB.step` | Idem KiCad |
| `adafruit-916-botao-metal-16mm.step` | `botao` | [adafruit/Adafruit_CAD_Parts](https://github.com/adafruit/Adafruit_CAD_Parts) @ `c128bce`, `916 metal button/916 Metal Button.step` | MIT |
| `adafruit-3258-microusb-painel.step` | `usb_painel` | Idem, `3258 USB Panel Mout Cable/3258 microUSB panel mount.step` | MIT |

Os nomes de `.zip` acima identificam o download original no GrabCAD; os zips
foram apagados em 08/10/2026 e só os arquivos usados ficaram aqui. Também
baixados e não usados: `tomada-eletrica-de-3-pinos…` (é um **plugue** macho,
não tomada), `Barramento de terra 12 Posições.STEP` (124 mm, não cabe na faixa
de rede), `bloque-de-terminales-2-rojo-1…` (borne de PCB de 2 vias, sem
componente definido) e `esp32-c3-mini-devkit-1…` (ESP32-C3, substituído pelo
DevKit V1 montado).

**Licença — antes de versionar.** O repositório é público. A
[central de ajuda do GrabCAD](https://help.grabcad.com/article/246-how-can-models-be-used-and-shared)
admite uso público não comercial com crédito e link ao autor, mas os
[Termos de Uso](https://grabcad.com/terms) concedem licença intransferível e não
sublicenciável, para uso próprio, interno e não comercial. Redistribuir os
arquivos (e o `arranjo_3d.step` gerado, que embute a geometria) num repositório
público não está claramente autorizado: pedir permissão aos autores ou manter
esses arquivos fora do git.

## Divergências modelo × peça do projeto

Os modelos são os mais próximos encontrados, não a peça comprada. Conferir
antes de usar o arranjo como referência dimensional:

- **`esp32`**: DevKit V1 montado — placa, furos, fileiras de pinos, WROOM-32 e
  micro-USB nas posições do footprint; botões EN/BOOT, AMS1117 e CP2102 em
  posição representativa; placa preta por escolha visual. Ocupa
  28,3 × 52,6 × 13,2 mm contra o volume de 29 × 52 × 13 (o micro-USB passa
  1,1 mm da borda). Para regerar: `QT_QPA_PLATFORM=offscreen FreeCAD
  mechanical/scripts/make_esp32_devkit_v1.py` (precisa do KiCad instalado).
- **`modulo_rele`**: o modelo tem **1 canal** (47 × 27 mm); o projeto usa o de
  2 canais LAFVIN (~50 × 39). Girado com a barra IN/5V/GND voltada para a
  divisória, passa 8 mm do volume em Y.
- **`terra_j3`**: barramento de terra de 6 posições (84,9 mm) contra um volume
  de 18 mm; a lista de compras pede borne DIN verde-amarelo em trilho (E14/E15).
  O IGES traz a barra como faces soltas e sem cor: o build lê com `Part.read` e
  pinta apoios de verde e barra/parafusos de latão.
- **`porta_fusivel`**: porta-fusível de **lâmina** (automotivo); a lista pede
  5×20 mm de vidro in-line (E12). Os rabichos de 138 mm são descartados no build.
- **`tomada_j1_corpo`**: moldura 45 × 25 mm, corpo ~44,2 × 21,2; o recorte
  `tomada_j1` é 45,5 × 23 — em X a moldura é **menor** que o recorte. IGES só de
  faces (sem sólido): no STEP reimportado vira um objeto por face.
- **`botao`**: Adafruit 916 é a versão **liga/desliga com anel de LED**; a lista
  (M1) pede momentâneo NA sem anel. Mesmo furo de 16 mm.
- **`usb_painel`**: corpo 12 × 9,8 mm contra o recorte `usb_w` × `usb_h` de
  16 × 9 (placeholder) — 0,8 mm mais alto que o recorte; flange com orelhas de
  parafuso de 25 mm que o recorte atual não prevê.
- **`prensa_cabo_corpo`**: o modelo prevê parede de 2,0 mm; com 2,4 mm a
  contraporca invade 0,4 mm a parede (só visual).
- **`hlk_pm01`**: pinos 4,9 mm abaixo do corpo; o volume de 15 mm não os incluía
  (passa 5 mm em Z). Eixo longo em X, com a saída DC voltada para a travessia.
- **`placa_aux`**: só a placa ilhada, sem C1/C2/C3/R1–R5 (o leiaute não
  existe ainda). O modelo de 60 × 40 é recortado no build para os 45 × 32 do
  volume; a altura de 26 mm do volume (definida pelo C1) não aparece. O STEP
  não traz cor: o build pinta fenolite e as ilhas de cobre.

Sem modelo (continuam caixa): `borne_rede` (a lista de compras troca os bornes
por conectores WAGO 221) e `travessia_fios`.

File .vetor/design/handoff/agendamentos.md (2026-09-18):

# Design Contract — Agendamentos

## Objetivo da experiência

Gerenciar horários automáticos de preparo, expressos como 'café pronto às' (não 'ligar às') — listar os existentes e criar um novo.

## Telas

Uma tela com lista de agendamentos + editor. No celular, lista e editor ficam empilhados na mesma página (desvio documentado no README — no design original eram duas pranchetas separadas); no desktop, ficam lado a lado.

## Hierarquia

1) Próximo agendamento ativo (destacado) no topo da lista; 2) demais agendamentos (ativo 'domingo', pausado); 3) nota informativa sobre funcionamento offline; 4) editor de novo agendamento (hora, dias, timeout, salvar/cancelar).

## Layout

Celular (<768): lista e editor empilhados verticalmente, editor com barra de cabeçalho própria (Cancelar/Novo agendamento/Salvar). Tablet (768–1023): mesmo empilhamento (wide--late só abre no desktop). Desktop (≥1024): lista e editor lado a lado (grid 1fr/1fr), sem a barra de cabeçalho do editor (usa botões Salvar/Cancelar no rodapé em vez disso).

## Componentes

card (variantes accent/default/muted+is-paused); switch (liga/desliga agendamento); days (indicador read-only de dias ativos, só celular); daypick (seletor de dias interativo no editor); wheel (seletor de hora em formato 24h); seg (controle segmentado de timeout); note (aviso informativo); btn--primary/btn--ghost (salvar/cancelar).

## Tokens

Agendamento ativo mais próximo usa borda --brand (card--accent). Pausado usa fundo --sunken + cor --dim (is-paused). Números do wheel em Space Grotesk 34px.

## Conteúdo

'Agendamentos', 'Novo', 'O café fica pronto quando você chega na cozinha. Dois agendamentos estão armados.', 'Próximo · amanhã', 'Café pronto às 06:45', 'Seg–sex · desliga sozinha após 8 min', 'Domingo', 'Café pronto às 08:30', 'Começo lento · desliga sozinha após 8 min', 'Pausado', 'Café pronto às 14:10', 'Turno da tarde · seg, qua', 'A base guarda estes horários na memória dela. Se o Wi-Fi cair de madrugada, o café acontece do mesmo jeito.', 'Café pronto às', 'Nestes dias', 'Desliga sozinha após', 'Não há sensor de água na base, então é o temporizador que encerra o preparo.', 'Salvo na base além da nuvem, para disparar offline.', 'Salvar agendamento'.

## Interações

O switch de cada card liga/desliga o agendamento sem abrir o editor. 'Novo' abre o editor para criar um agendamento. No editor: girar o wheel ajusta a hora; tocar um dia no daypick alterna ativo/inativo; o seg de timeout tem seleção única; 'Salvar agendamento' persiste; 'Cancelar' descarta.

## Estados

### State: populated

Trigger:
Tela aberta com agendamentos já criados.

Expected behavior:
Lista mostra o próximo agendamento em destaque, seguido dos demais (ativos e pausados) em ordem.

Evidence:
Prototype

### State: disabled

Trigger:
Usuário desativa o switch de um agendamento.

Expected behavior:
O card muda para o tratamento visual 'pausado' (fundo --sunken, texto --dim, eyebrow atenuado) e o switch move para a posição desligada; o agendamento deixa de disparar mas continua na lista.

Evidence:
Prototype

### State: offline

Trigger:
Conexão Wi-Fi ou nuvem cai.

Expected behavior:
Os agendamentos já salvos continuam disparando pelo relógio interno da base, sem depender do app ou da nuvem — o texto do app afirma isso explicitamente, mas nenhuma tela mostra um indicador visual de 'base offline' nesta lista.

Evidence:
Prototype

### State: permission denied

Not applicable:
Verificado no backend (2026-09-18): `AgendamentoService.kt` importa `PapelDispositivo` mas não checa `.papel` em nenhum dos seus métodos — criar/editar/excluir/ativar agendamento está disponível a qualquer usuário vinculado ao dispositivo, incluindo convidado. Corrigindo minha própria correção anterior — não é lacuna, é a regra de negócio real (só administração do dispositivo e baixa de descalcificação são exclusivas do proprietário).

### State: loading

OPEN_QUESTION
Estado não avaliado nesta extração do protótipo — nem especificado, nem marcado
como não aplicável.

Impact:
A implementação não deve assumir o comportamento deste estado sem confirmação —
esta lacuna precisa ser resolvida antes ou durante a implementação.

### State: empty

OPEN_QUESTION
Estado não avaliado nesta extração do protótipo — nem especificado, nem marcado
como não aplicável.

Impact:
A implementação não deve assumir o comportamento deste estado sem confirmação —
esta lacuna precisa ser resolvida antes ou durante a implementação.

### State: error

OPEN_QUESTION
Estado não avaliado nesta extração do protótipo — nem especificado, nem marcado
como não aplicável.

Impact:
A implementação não deve assumir o comportamento deste estado sem confirmação —
esta lacuna precisa ser resolvida antes ou durante a implementação.

### State: partial failure

OPEN_QUESTION
Estado não avaliado nesta extração do protótipo — nem especificado, nem marcado
como não aplicável.

Impact:
A implementação não deve assumir o comportamento deste estado sem confirmação —
esta lacuna precisa ser resolvida antes ou durante a implementação.

### State: success

OPEN_QUESTION
Estado não avaliado nesta extração do protótipo — nem especificado, nem marcado
como não aplicável.

Impact:
A implementação não deve assumir o comportamento deste estado sem confirmação —
esta lacuna precisa ser resolvida antes ou durante a implementação.

## Responsividade

Celular (<768): lista e editor empilhados, editor com barra de cabeçalho própria. Tablet (768–1023): mesmo empilhamento do celular para este bloco. Desktop (≥1024): lista e editor lado a lado, editor sem a barra de cabeçalho (usa botões no rodapé).

## Acessibilidade

Os cards de agendamento usam <span class="switch"> sem role="switch" nem aria-checked — não é um controle nativo acessível por teclado ou leitor de tela. O daypick e o seg do editor usam <button> reais (acessíveis por teclado), mas sem aria-pressed para indicar seleção.

## Restrições

Sem sensor de água — o timeout é quem encerra o preparo, não um sensor de nível. Horários e dias ficam salvos na própria base (não só no app/nuvem), garantindo disparo offline.

## Referências

- docs/docs_interface/prototype/schedule.html
- docs/docs_interface/prototype/assets/cafey.css
- docs/docs_interface/prototype/README.md

## Decisões

CONFIRMED
O agendamento ativo mais próximo recebe tratamento visual diferenciado (card--accent) dos demais ativos.
Source: schedule.html (.card.card--accent vs. .card sem modificador)

CONFIRMED
Lista e editor de novo agendamento vivem na mesma página — desvio do design original, que separava 'lista' e 'novo agendamento' em pranchetas distintas no celular.
Source: docs/docs_interface/prototype/README.md (item 4 dos desvios)

ASSUMED
O botão 'Novo' sempre abre um editor vazio (não pré-populado); editar um agendamento existente reaproveitaria o mesmo editor, mas o protótipo não mostra esse fluxo — só criação.
Reason: Nenhuma tela mostra um card levando a um editor pré-preenchido; a suposição segue o padrão mais comum de reuso de editor, mas não é confirmada pelo protótipo.

## Estado de implementação (observado em 2026-09-18)

`ScheduleScreen.kt`/`ScheduleViewModel.kt` (Compose Multiplatform) resolvem a questão aberta de lista vazia ("Nenhum agendamento ainda."), além de loading e um estado "salvando" no botão. Também adicionam editar/excluir, que este contrato não previa.

Divergências reais com este contrato, documentadas no próprio código:
- O "wheel" animado de hora foi substituído por um campo de texto validado (HH:mm), com erro exibido por campo — na prática mais acessível que o `<span class="switch">` do protótipo (aqui é um `Switch` real do Material3, com semântica de toggle nativa).
- Não existe o seletor "desliga sozinha após" — não há campo correspondente em `CriarAgendamentoRequest`/`AtualizarAgendamentoRequest` (a duração é do dispositivo inteiro, não por agendamento).
- Sem o destaque visual "próximo · amanhã" (card--accent) — a lista atual não distingue visualmente o próximo agendamento dos demais.

Correção (2026-09-18, checkout sincronizado com `origin/main`): a navegação (trilho de ícones/sidebar por breakpoint) já adapta em nível de app inteiro via `CafeyNavHost.kt`/`NavShellSizeClass.kt` — o que eu tinha registrado como "sem trilho/sidebar" não é mais verdade em nenhuma tela. O que continua faltando é só o grid de duas colunas *dentro* desta tela (lista ao lado do editor no desktop) — a lista e o editor aqui ainda ocupam a coluna inteira, empilhados.

Fontes: `apps/shared/src/commonMain/kotlin/br/com/tavaressan/cafey/shared/ui/schedule/ScheduleScreen.kt`, `ScheduleViewModel.kt`.

## Questões abertas

OPEN_QUESTION
Não há composição para 'nenhum agendamento criado ainda' (lista vazia). **Resolvido na implementação real (ver seção "Estado de implementação" acima) — este contrato ainda não refletia isso.**
Impact: A tela pode ficar sem conteúdo de destaque na primeira execução do app, antes do usuário criar o primeiro agendamento.

OPEN_QUESTION
Falha ao salvar um agendamento (ex.: base não responde) não tem feedback visual definido, nem confirmação de sucesso após salvar.
Impact: O usuário pode não saber se o agendamento foi realmente persistido na base.

OPEN_QUESTION
Comportamento de dois agendamentos no mesmo horário (conflito) não está definido.
Impact: Pode ser necessário decidir se o app impede, avisa, ou permite silenciosamente a sobreposição antes de implementar o editor.

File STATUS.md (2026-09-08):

# Estado atual

Data: 31/08/2026. Fase 1 do cronograma (24/08 a 04/09).

Esquemático revisado: netlist conferida nó a nó com `kicad-cli`, ERC limpo
(salvo avisos esperados de GPIO livre e duas exclusões documentadas). Início da
prototipação embarcada no Wokwi — ver `firmware/`.

> **Atualização 08/09/2026:** o esquemático recebeu correções (relé active-low,
> R1 pull-up para +3V3, F1 10 A T). **ERC re-rodado com `kicad-cli` 10.0.5:
> 0 erros, 22 avisos** (os mesmos 21 GPIO livres + 1 `pin_to_pin` U1.GND↔U2.-Vout
> já documentados). Netlist reconferida: `RELE_IN` = {GPIO26, K3.IN, R1};
> `+3V3` = {U1.16, R2, R1}; `L_FONTE` = {F1.2, K3.COM, U2.L}. PDF regenerado.
> Ver "Revisão de compras e correções (08/09/2026)".

## Decisões fechadas

| Item | Decisão |
|---|---|
| Cafeteira | Britânia CP30 Inox, 800 W, 127 V, chave mecânica KCD1-106 (~6,3 A) |
| Alimentação 5 V | Módulo AC-DC HLK-PM01 embutido (5 V, 600 mA, isolado); prototipagem por USB |
| Módulo de relé | Módulo de 2 canais em estoque (LAFVIN), **1 canal em uso**; bobina 5 V, optoacoplador, ≥10 A, **gatilho de nível BAIXO** (HL-52S: LOW = liga) — ver "Revisão de compras e correções (08/09/2026)" |
| Isolamento | Fonte única, jumper JD-VCC mantido, ruído tratado por desacoplamento |
| LED | RGB discreto de cátodo comum (símbolo `Device:LED_RGBK`) |
| Proteção | Fusível **F1 = 10 A / 250 V retardado (T)** na entrada, em série com o caminho da carga (`L_REDE → F1 → relé COM → NO → tomada`); protege toda a fiação do módulo, incluindo a carga. Dimensionado entre a cafeteira (~6,3 A) e o contato do relé (10 A). Decisão de 08/09: manter a filosofia do esquemático (fusível protege a carga), **não** rebaixar para um fusível só do ramo do HLK-PM01 |
| MCU | DOIT ESP32 DevKit V1, 30 pinos |
| Esquemático | Folha única A4, KiCad 10.0.5 |

Duas decisões acima divergem da especificação e o texto dela ainda não foi
atualizado:

1. A §4.4 dava a alimentação como pendente. Está resolvida: HLK-PM01. O
   argumento decisivo foi que a tomada fêmea da base é chaveada pelo relé, então
   um carregador externo exigiria uma segunda tomada de parede.
2. A §4.5 e a §9 afirmam "isolamento galvânico por optoacoplador separando o
   ESP32 do lado da carga". Com o jumper JD-VCC de fábrica, isso é falso: a
   bobina compartilha rail e GND com o ESP32, e o optoacoplador não isola nada.
   A separação entre lógica e rede é dada pela rigidez dielétrica do relé. O
   texto precisa ser corrigido antes da banca.

## Pinagem definida

| Função | GPIO | Pino do símbolo | Componentes associados |
|---|---|---|---|
| Alimentação | VIN | 1 | +5V |
| Terra | GND | 2 | GND |
| Referência 3,3 V | 3.3v | 16 | +3V3 |
| Sinal do relé | GPIO26 | 7 | R1 10 kΩ **pull-up para +3V3** (módulo active-low) |
| Botão | GPIO27 | 6 | R2 10 kΩ pull-up, C3 100 nF |
| LED vermelho | GPIO21 | 26 | R3 220 Ω |
| LED verde | GPIO22 | 29 | R4 100 Ω |
| LED azul | GPIO23 | 30 | R5 100 Ω |

R1 é pull-up para +3V3 porque o módulo é active-low (LOW = relé ligado):
com o GPIO em alta impedância no boot, R1 mantém a entrada IN em nível ALTO
= relé desligado. Repouso e falha passam a ser o mesmo estado seguro. O
firmware reforça isso forçando o pino em ALTO antes de configurar o GPIO
(`firmware/drivers/relay.cpp`).

GPIO12 foi evitado (nível alto no boot impede a partida); GPIO2, 5 e 15 foram
evitados (strapping); GPIO34, 35, 36 e 39 são somente entrada.

O símbolo `ESP32_30Pin` declara o pino 16 (3V3) como entrada de energia; na
placa real o 3V3 é saída do regulador de bordo. Por isso a rede `+3V3` leva um
`PWR_FLAG` — curativo de ERC, sem efeito físico. Corrigir no símbolo algum dia.

## Esquemático — referências (mudaram após reanotação)

| Ref | Componente |
|---|---|
| P1 | Cabo macho NBR 14136 (`Connector:Conn_Plug_3P_Protected`) |
| J1 | Tomada fêmea NBR 14136 (`Connector:Conn_Receptacle_3P_Protected`) |
| J3 | Borne de aterramento DIN verde-amarelo — ponto de junção do PE (passa-através rede→tomada), no nó `Earth_Protective`. Gabinete plástico FDM, sem massa metálica a aterrar (era "terra da chapa de aço" na versão em chapa) |
| U1 | ESP32 DevKit V1 |
| U2 | HLK-PM01 (`Converter_ACDC:HLK-PM01`) |
| K3 | Módulo relé, gatilho baixo, 2 canais (1 em uso) (`relay_module:Relay_Module_1CH`, símbolo único do projeto — representa o canal usado) |
| F1 | Fusível | C1/C2/C3 | Capacitores (C3 = antigo C4, buraco fechado) |

## Esquemático — o que está pronto

- Bloco de potência: P1 (cabo macho) → F1 → COM/NO de K3 → J1 (tomada fêmea).
  Neutro e terra passam diretos.
- J3 (borne de aterramento DIN, ex-"terminal olhal da chapa") e o símbolo
  `Earth_Protective` no nó de terra; a rede se chama `Earth_Protective` e liga
  P1.PE, J1.PE e J3.
- PE e GND são redes separadas, sem ponto de encontro. A saída do HLK-PM01 é
  isolada e seu negativo não vai ao terra de proteção.
- Derivação da fase para a fonte entre F1 e o contato do relé, via rótulo
  `L_FONTE`. `L_REDE` = fase da rede antes do fusível; `L_SAIDA` = fase chaveada
  para a tomada.
- Todos os componentes com símbolo dedicado (HLK-PM01, relé, plugue/tomada
  protegidos) e campos de Valor preenchidos.
- `PWR_FLAG` em `+3V3`, `L_REDE` e `L_SAIDA` (o `+5V` e o `GND` são dirigidos
  pelos pinos de saída do HLK-PM01).
- Anotação feita; ERC rodado.
- Netlist conferida nó a nó com `kicad-cli export netlist`.
- Notas de texto no bloco de potência (tensão, corrente, aviso de validação).

## Esquemático — o que falta

- [ ] Atribuir footprints a todos os componentes (nenhum tem footprint ainda) —
      pré-requisito do PCB
- [ ] Dois avisos de ERC ficam como exclusão documentada: `power_out ↔ power_out`
      em `N` e em `Earth_Protective` (passagem direta plugue→tomada, inerente aos
      símbolos `*_3P_Protected`)
- [ ] Aviso `pin_to_pin` entre U1.GND (bidirecional) e U2.-Vout — inofensivo
- [ ] 21 avisos de "pino não conectado" nos GPIOs livres do U1 — esperados

## Pendências de bancada

Nenhuma delas é decisão — são verificações contra o componente físico.

- [ ] Conferir serigrafia do DevKit pino a pino contra o símbolo `ESP32_30pin`
- [ ] Conferir ordem VCC/GND/IN e NC/COM/NO na serigrafia do módulo de relé
      (varia por fabricante; trocar COM com NO inverte a lógica da cafeteira)
- [ ] Identificar as pernas físicas do LED RGB com multímetro em teste de
      diodo — a numeração do símbolo é lógica, não física
- [ ] Validação da montagem elétrica por profissional (marco de 02/10)

## Compras pendentes

Lista completa e revisada em `docs/lista-compras-cafeteira.md` (revisão de
08/09/2026). Fusível fixado em **10 A T** (não 8 A): fica no limite do contato
do relé, protege a fiação do módulo e o cabo; menos abertura espúria que 8 A
sobre 6,3 A. Itens `MEDIR` (E2 tomada, E10 prensa-cabo, M1 botão) compram
primeiro e alimentam o modelo mecânico.

## Revisão de compras e correções (08/09/2026)

Revisão técnica da lista de compras cruzada com esquemático, firmware e modelo
mecânico. Decisões tomadas nesta sessão e o que falta aplicar.

### Decisões

| Tema | Decisão |
|---|---|
| Filosofia do fusível | Manter o esquemático: F1 em série com a carga, protege todo o módulo. **Não** rebaixar para fusível só do ramo do HLK-PM01. |
| Valor de F1 | 10 A / 250 V **retardado (T)**. |
| Gatilho do relé | **Active-LOW** (firmware/Wokwi estavam certos; esquemático e STATUS estavam errados). R1 vira pull-up para +3V3. |
| Módulo de relé | É de **2 canais** (LAFVIN), usa 1. Atualizar o modelo mecânico para o volume real de 2 canais. |
| Botão de painel | **16 mm** metálico momentâneo NA. Atualizar `furo_botao` no modelo (era 12 mm). |
| Cabo de força (E1) | **3G1,0 mm²**, ⌀ externo ≤ 8 mm (entra no PG9 — não subir para 1,5 mm²). |
| Ponto de terra (PE) | **Borne de aterramento DIN verde-amarelo** (mantém o papel do J3). Gabinete plástico não tem massa a aterrar. |
| Bonding do botão/USB metálicos ao PE | **Em aberto** — decisão do profissional habilitado no marco de 02/10. |

### Correções já aplicadas nesta sessão

- `hardware/pi_dsm_26_2.kicad_sch`:
  - `K3` Value: "1 canal, gatilho alto" → "2 canais (1 em uso), gatilho baixo (HL-52S, LOW=liga)".
  - `F1` Value: "10 A / 250 V" → "10 A T / 250 V".
  - R1 pull-down → pull-up: símbolo `#PWR08` trocado de `power:GND` para `power:+3V3` (rotação 180) no pino inferior de R1.
  - `J3` Value: "Terra da chapa de aço — terminal olhal" → "Borne de aterramento DIN verde-amarelo…".
  - ERC re-rodado (0 erros / 22 avisos esperados); `pi_dsm_26_2.pdf` regenerado.
- `STATUS.md`: tabela de decisões, pinagem, referências, compras pendentes (este arquivo).
- `mechanical/params/parametros_3d.csv`: `furo_botao` 12 → 16 mm.
- `mechanical/params/componentes_3d.csv`: `modulo_rele` redimensionado para módulo de 2 canais.
- `mechanical/FUROS.md`: nota do `furo_botao` (12 → 16 mm) e do porta-fusível.
- `docs/lista-compras-cafeteira.md`: criado.

### Falta aplicar (não dá para fazer neste ambiente)

- [x] ERC re-rodado (`kicad-cli` 10.0.5): 0 erros, 22 avisos esperados. Netlist
      reconferida. PDF regenerado.
- [ ] Abrir no KiCad e conferir a **aparência** do símbolo `#PWR08` (trocado de
      `power:GND` para `power:+3V3`, rotação 180 por edição de texto) e reanotar
      as refs de power se necessário — cosmético, o ERC/netlist já estão corretos.
- [ ] Regenerar o modelo mecânico (`freecadcmd mechanical/scripts/build_peca1_3d.py`
      etc.) para propagar `furo_botao = 16` e o novo volume do relé; conferir
      `check_peca*.py`.
- [ ] Medir a placa de relé 2 canais LAFVIN real e ajustar o envelope
      `modulo_rele` com o valor medido (o valor atual é estimado).
- [ ] Reposicionar `modulo_rele` no compartimento de rede se o volume maior
      colidir com `hlk_pm01` ou `porta_fusivel`.
- [ ] Atualizar a §4.5 e a §9 da especificação (isolamento) — pendência antiga,
      ainda aberta.
- [ ] Conferir na bancada se o módulo de relé físico realmente liga com IN=LOW.
- [ ] Verificar se o plugue da CP30 tem o 3º pino (terra) populado.

## Marcos

| Data | Critério |
|---|---|
| 04/09 | Relé aciona carga por comando do ESP32; backend autentica ponta a ponta |
| 20/09 | Submissão do artigo EnGeTec |
| 25/09 | Comando do mobile chega à base via AWS IoT |
| 02/10 | Montagem elétrica validada por profissional |
| 09/10 | Agendamento dispara offline; histórico com eventos reais |
| 16/10 | Projeto pronto para a banca |

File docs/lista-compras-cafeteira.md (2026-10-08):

# Lista de compras — Cafeteira Conectada

Projeto: retrofit IoT da cafeteira Britânia CP30 (800 W, 127 V, ~6,3 A).
Revisão: 2026-09-08. Prazo de defesa: 2026-10-16.

Esta é a versão revisada da lista, cruzada com o esquemático
(`hardware/pi_dsm_26_2.kicad_sch`), o firmware (`firmware/`) e o modelo
mecânico (`mechanical/`). As decisões de revisão estão registradas em
`STATUS.md`, seção "Revisão de compras e correções (08/09/2026)".

## Instruções para quem for comprar

1. Comprar **apenas** os itens da seção "Comprar". A seção "NÃO comprar" existe
   para evitar duplicidade — esses itens já estão em estoque.
2. Cada item traz `busca` (termo de pesquisa), `exigido` (especificação que não
   pode faltar) e `rejeitar` (variantes erradas comuns). Se nenhum resultado
   atender a `exigido`, **não substituir por aproximação** — reportar o item
   como não resolvido.
3. Preços e disponibilidade não foram verificados. Conferir no momento da compra.
4. Prioridade P1 antes de P2. Os itens marcados `MEDIR` devem chegar primeiro:
   as cotas deles alimentam o modelo mecânico, que está em análise.
5. Ao final, gerar um resumo com: itens no carrinho, itens não resolvidos, total.

---

## Comprar — P1 · Rede elétrica 127 V

| ID | Item | Qtd | Busca | Exigido | Rejeitar |
|---|---|---|---|---|---|
| E1 | Cabo de força com plugue | 1 | `cabo de força tripolar 3G1,0mm 2P+T NBR 14136 1,5m` | 2P+T, 10 A, **condutor 1,0 mm²**, comprimento 1,2–2,0 m, **⌀ externo ≤ 8 mm** (tem de entrar no PG9 do E10) | Bitola 0,75 mm²; **1,5 mm² (⌀ externo grande demais para PG9)**; plugue sem terra; padrão americano/europeu |
| E2 | Tomada fêmea de painel `MEDIR` | 1 | `tomada femea painel 2P+T 10A NBR 14136` | **10 A** (pinos 4,0 mm), fixação em painel ou embutir | Versão 20 A (pinos 4,8 mm); tomada de parede sem furação frontal |
| E3 | Conector de emenda com alavanca | 4 | `conector emenda WAGO 221-412 2 vias` | 2 vias, até 4 mm², com alavanca | Modelos push-in sem alavanca (773/2273) |
| E4 | Conector de emenda com alavanca | 2 | `conector emenda WAGO 221-413 3 vias` | 3 vias, até 4 mm², com alavanca | Idem E3 |
| E5 | Cabo flexível preto | 1 m | `cabo flexivel 1,5mm 750V preto` | 1,5 mm², isolação 750 V | 300 V; cabo rígido |
| E6 | Cabo flexível azul | 1 m | `cabo flexivel 1,5mm 750V azul` | Idem E5 | Idem E5 |
| E7 | Cabo flexível verde-amarelo | 1 m | `cabo flexivel 1,5mm 750V verde amarelo` | Idem E5 | Verde liso (terra deve ser verde-amarelo) |
| E8 | Terminais tubulares pré-isolados | 20 | `terminal tubular ilhos pre-isolado 1,5mm` | Para 1,5 mm², pré-isolado | Terminal olhal, garfo ou pino chato |
| E9 | Termorretrátil | 1 m ⌀2,5 + 1 m ⌀4 | `tubo termorretratil 2,5mm 4mm kit` | Razão 2:1 | — |
| E10 | Prensa-cabo `MEDIR` | 1 | `prensa cabo PG9 nylon com porca` | PG9, faixa de aperto compatível com o ⌀ externo de E1 | Metálico (rosca em plástico impresso); PG7 ou PG11 sem conferir o cabo |
| E11 | Módulo AC-DC | 2 | `HLK-PM01 fonte AC-DC 5V 3W` | Saída 5 V, 600 mA, entrada 100–240 V. **1 em uso + 1 reserva** (não é arquitetura de duas fontes) | HLK-PM03 (3,3 V); HLK-PM12 (12 V); HLK-5M05 (formato diferente) |
| E12 | Porta-fusível **in-line** | 1 | `porta fusivel 5x20 in-line com rabicho` | Para fusível 5×20 mm, **corpo fechado, com rabicho, para fixação por abraçadeira** | **Porta-fusível de painel** (exige furo que o modelo mecânico proíbe); de PCB; de engate rápido |
| E13 | Fusível de vidro | 5 | `fusivel vidro 5x20 10A retardado` | 5×20 mm, **10 A**, retardado (tipo T) | Ação rápida (F); ≤ 6,3 A (abre com a carga); acima de 10 A |
| E14 | Borne de aterramento DIN | 1 | `borne aterramento trilho DIN verde amarelo 4mm` | Verde-amarelo, para trilho DIN 35 mm, 4–6 mm² | Borne comum (não identificado como terra); tipo parafuso de chapa |
| E15 | Trilho DIN + travas | 1 | `trilho DIN 35mm + trava fim de trilho` | ~5 cm de trilho 35 mm + 2 travas de fim de trilho | — (alternativa: dispensar e projetar clipe no boss impresso — decisão do modelo mecânico) |

**Intenção de projeto de E12/E13 (revisada 08/09/2026):** F1 protege **todo o
módulo, incluindo a carga** — está em série no caminho
`L_REDE → F1 → relé COM → NO → tomada`. Dimensionado entre a cafeteira
(~6,3 A) e o contato do relé (10 A). O disjuntor da instalação continua sendo a
proteção primária de sobrecorrente; F1 limita o let-through numa falta interna
do módulo e protege o contato do relé.

**Intenção de projeto de E14/E15:** o gabinete é impresso em plástico (FDM) —
não há massa metálica a aterrar. O PE entra pelo cabo, passa pelo borne DIN e
sai para a tomada da cafeteira. O borne é um ponto de junção **identificável
como terra** para a inspeção elétrica, mais robusto contra puxão que um
conector de alavanca. Continuidade cabo→tomada é o item crítico de segurança.

## Comprar — P2 · Painel e montagem eletrônica

| ID | Item | Qtd | Busca | Exigido | Rejeitar |
|---|---|---|---|---|---|
| M1 | Botão momentâneo de painel `MEDIR` | 1 | `push button metalico 16mm momentaneo NA painel` | ⌀ furo **16 mm**, momentâneo (NA), com porca de fixação | Retentivo/trava (latching); versão com anel de LED; 12 mm ou 19 mm |
| M2 | Suporte/aro para LED | 1 | `suporte aro para LED 5mm painel` | Para LED 5 mm | Para 3 mm ou 10 mm |
| M3 | Placa ilhada perfurada | 2 | `placa ilhada perfurada 5x7cm fenolite` | Furos a 2,54 mm, ilhas individuais | Placa de fita/barramento contínuo; placa virgem sem furos |
| M4 | Barra de pinos fêmea | 2 | `barra de pinos femea 1x40 2,54mm` | Passo 2,54 mm, cortável | Passo 2,00 mm; barra empilhável alta |
| M5 | Barra de pinos macho | 1 | `barra de pinos macho 1x40 2,54mm` | Passo 2,54 mm | Passo 2,00 mm |
| M6 | Fio rígido para montagem | 1 kit | `fio rigido 22AWG kit cores jumper solda` | 22 AWG, rígido, ≥3 cores | Fio flexível fino sem estanhar |
| M7 | Conectores JST-XH (rabichos do LED e do botão) | 4 vias: 2 conjuntos; 2 vias: 2 conjuntos (1 + reserva cada) | `conector JST XH 4 vias cabo pre crimpado header 180 graus` / `... 2 vias ...` | Passo 2,5 mm; header macho PTH vertical (180°) + cabo pré-crimpado ≥ 10 cm (4 vias) e ≥ 15 cm (2 vias) | JST-PH (passo 2,0 mm); JST-SM; header SMD |
| M8 | Cabo extensor micro-USB de painel `MEDIR` | 1 | `cabo extensor micro usb painel macho femea com parafuso` | Micro-B macho → micro-B fêmea com flange de fixação por parafuso; 20–30 cm; dados (não só carga) | Só carga; USB-C; sem flange de painel |

## Verificar em estoque antes de comprar (Alfabra)

Comprar somente o que não existir:

| ID | Item | Qtd |
|---|---|---|
| A1 | Insertos roscados a quente, latão M3 × 5 mm | 20 |
| A2 | Ponteira M3 de inserto para ferro de solda | 1 |
| A3 | Parafuso M3 inox 8 mm | 10 |
| A4 | Parafuso M3 inox 10 mm | 10 |
| A5 | Parafuso M3 inox 12 mm | 10 |
| A6 | Pés de borracha adesivos | 4 |
| A7 | Retalho de chapa 1 mm (alumínio ou aço) para interposto térmico | 1 |
| A8 | Multímetro | 1 |

## NÃO comprar — já em estoque

- ESP32 DEVKIT V1 — kit LAFVIN + 1 sobressalente
- Módulo de relé **2 canais** 10 A — kit LAFVIN + 1 sobressalente (usa 1 canal;
  é **active-low** / gatilho de nível BAIXO — HL-52S)
- LED RGB 5 mm, pushbutton de protoboard, resistores 220 Ω, protoboard
  MB-102, jumpers, cabo USB — kit LAFVIN
- Resistores 10 kΩ (R1, R2) — em estoque, fora do kit LAFVIN, que só traz
  220 Ω (confirmado em 08/10/2026; ver `docs_materiais/esp32_kit.md`, A1)
- Capacitores C1 470 µF / 16 V eletrolítico, C2 e C3 100 nF — Alfabra
  (confirmado em 08/10/2026)
- Filamento PETG e ASA — Alfabra
- Estanho para solda — Alfabra
- Alicate de crimpar terminal tubular — Alfabra
- Termômetro IR / termopar — empréstimo Alfabra

---

## Contagem de conectores (derivada do esquemático)

Nós de rede e o que se junta em cada um:

| Nó | Pontos físicos | Conector |
|---|---|---|
| `L_REDE` | cabo P1 (L) · entrada do F1 | 1× WAGO 221-412 (2 vias) |
| `L_FONTE` | saída do F1 · relé COM · HLK-PM01 (L) | 1× WAGO 221-413 (3 vias) |
| `L_SAIDA` | relé NO · tomada J1 (L) | 1× WAGO 221-412 (2 vias) |
| `N` | cabo P1 (N) · tomada J1 (N) · HLK-PM01 (N) | 1× WAGO 221-413 (3 vias) |
| `PE` | cabo P1 (PE) · tomada J1 (PE) | borne DIN E14 (não usa WAGO) |

Necessário: 2× 221-412 + 2× 221-413. A lista pede 4× + 2× — os 2× 221-412
extras ficam como reserva.

## Sequenciamento

Comprar **E2, M1 e E10 primeiro**, isoladamente se necessário. Os três definem
recortes e furos do gabinete, e o modelo mecânico está em análise. Medir as
peças reais e reconciliar com o modelo antes da aprovação evita um ciclo de
impressão de peça grande.

O restante pode ir em compra única.

## Verificação pós-compra

- [ ] E2 é 10 A (pinos de 4,0 mm), não 20 A
- [ ] ⌀ externo de E1 está dentro da faixa de aperto de E10 (≤ 8 mm para PG9)
- [ ] E11 tem marcação "HLK-PM01" e "5V" impressa no corpo
- [ ] E1 tem bitola **1,0 mm²** indicada na capa
- [ ] E13 é **10 A retardado (T)**, não ação rápida e não 500 mA
- [ ] E12 é **in-line com rabicho**, não de painel
- [ ] Recorte de E2 (`tomada_j1`), furo de M1 (`furo_botao`, hoje 16 mm no
      modelo) e corpo de E10 (`prensa_cabo` Ø15) medidos e enviados para o
      modelo mecânico
- [ ] M4 permite soquetar o DevKit de 30 pinos (15 por lado após corte)
- [ ] Plugue da CP30: confirmar se o 3º pino (terra) está populado

## Pendências para o profissional habilitado (marco de 02/10)

- Bondar ao PE o botão metálico M1 e o conector USB (lado da baixa tensão), ou
  mantê-los só no SELV confiando na barreira do HLK-PM01 + divisória?
- Declarar na defesa: o módulo pressupõe alimentação por circuito com
  **DR 30 mA** a montante (exigência NBR 5410 para circuito de cozinha).

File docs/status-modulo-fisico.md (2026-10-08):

# Módulo físico — pedestal

**Atualização 08/09/2026 (issue #116) — pivô para impressão 3D.** A
tecnologia de fabricação mudou de chapa de inox dobrada para impressão 3D
(FDM). O que segue neste documento, até a seção "Atualização — impressão 3D",
é o histórico da decisão original em chapa (preservado, não apagado); a
seção final documenta o que mudou e por quê. Os scripts de modelagem também
foram preservados (`mechanical/scripts/build_peca1.py` etc. continuam
funcionando) e os novos scripts `*_3d.py` implementam a versão atual — ver
`mechanical/README.md`.

---

Data: 01/09/2026. Sessão de decisão de arquitetura da peça. Nenhuma geometria
modelada ainda; o que segue é o que entra no CAD.

Ferramenta escolhida: FreeCAD com a workbench SheetMetal (addon, instalável pelo
Addon Manager). Motivo: é a única das candidatas que desdobra chapa aplicando
fator K e exporta a planificação. OpenSCAD foi descartado por não ter nenhum
conceito de dobra ou linha neutra.

O modelo será revisado por profissional de desenho CAD e dobra na empresa. Por
isso tudo depende de parâmetros: a crítica do revisor vira valor na planilha, não
retrabalho de geometria.

## Forma geral

Pedestal. A cafeteira apoia sobre o módulo; a eletrônica fica embaixo.

| Parâmetro | Valor | Origem |
|---|---|---|
| Pegada | 260 × 210 mm | catálogo da cafeteira (257 × 198), com folga |
| Altura externa | 45 mm | empilhamento dos módulos |
| Altura interna livre | 41,4 mm | descontados tampo, aba e fundo |
| Pés | 4 × 10 mm, EPDM ou silicone, antiderrapante | |
| Elevação total | 55 a 60 mm | conforme apoio da cafeteira |
| Massa em operação | ~2,9 kg | 1,64 kg mais 1,2 L |

## Construção

Duas peças.

**Peça 1 — dobrada.** Tampo, quatro saias de 45 mm para baixo e quatro abas de
12 mm dobradas para dentro na borda inferior das saias. Oito dobras.

**Peça 2 — plana.** Fundo removível, apoiado sobre as abas, sem nenhuma dobra.

| Item | Decisão |
|---|---|
| Cantos | Aba de 20 mm saindo das saias frontal e traseira, sobrepondo a face interna das laterais |
| Fixação dos cantos | 2 por canto, 8 no total. Parafuso M3 inox (premissa; rebite é alternativa paramétrica) |
| Fixação do fundo | 8 × M3 em porca-rebite nas abas do fundo |
| Alívio de canto | Entalhe de 2,4 mm no encontro das dobras |
| Planificação | ~366 × 316 mm; chapa bruta ~400 × 350 mm |

A aba do fundo não existe só para prender a tampa: ela é a aba de retorno que
enrijece as saias e responde ao risco de flexão do tampo sob carga.

**Ordem de dobra:** abas do fundo primeiro, com a chapa ainda plana; saias
depois. Ao contrário, a viradeira não alcança o interior de uma caixa de 45 mm de
profundidade por 260 mm de largura. Isso vai na nota do desenho.

## Arranjo interno

Rede entra e sai pela traseira; baixa tensão vive na frente. Os dois caminhos
correm em faixas paralelas e nunca lado a lado.

| Faixa | Profundidade | Conteúdo |
|---|---|---|
| Rede, 127 V | 120 mm, traseira | Prensa-cabo, bornes com tampa, F1, HLK-PM01, módulo de relé, tomada J1, terra J3 |
| Divisória | 2 a 3 mm | Policarbonato ou acrílico, altura plena, em cantoneiras na chapa do fundo |
| Baixa tensão, 5 V | 84 mm, frontal | ESP32, placa auxiliar de R e C, LED, botão |

O módulo de relé e o HLK-PM01 são híbridos e ficam do lado da rede, com os
terminais de baixa tensão voltados para a divisória.

**Travessia única**, por rasgo com passa-fio: +5 V e GND do HLK-PM01, mais VCC,
GND e IN do relé. Cinco fios, perpendiculares à divisória.

Nenhum condutor de rede a menos de 10 mm da divisória. Folga de projeto, não
número normativo; quem valida é o eletricista no marco de 02/10.

C1 (470 µF) e C2 (100 nF) montados na placa auxiliar, do lado da baixa tensão, na
entrada do rail. O ideal eletrônico seria junto à bobina, mas isso colocaria
eletrólito do lado da rede. Se o ESP32 resetar ao acionar o relé na bancada, o
diagnóstico já está escrito.

**LED de status (decidido em 08/10/2026).** O LED fica na parede frontal
(Peça 1) e a placa auxiliar sobre o fundo (Peça 2), que abre por baixo para
trocar o fusível. Por isso a ligação é desconectável: rabicho de 4 fios (R, G,
B e cátodo comum) de ~10 cm, com conector JST-XH de 4 vias (M7): o cabo
pré-crimpado é soldado nos terminais do LED e isolado com termorretrátil
Ø 2,5 mm (E9), e o header macho fica no canto frontal direito da placa
auxiliar. Um plugue único e polarizado, em vez de 4 jumpers Dupont avulsos, não
deixa inverter nem deslocar os fios ao fechar o fundo. O passo do XH (2,5 mm)
difere em 0,12 mm da placa ilhada (2,54 mm) em 4 pinos — conferir o encaixe na
montagem. R3, R4 e R5 ficam na placa. No arranjo 3D o percurso é de ~26 mm
para trás e ~23 mm para baixo; os 10 cm deixam folga para soltar o conector com
o fundo aberto. Prender o cabo com abraçadeira. Não usar o fio rígido 22 AWG
(M6) no rabicho: ele quebra com a dobra a cada abertura.

**Botão (decidido em 08/10/2026).** Mesma lógica do LED: o botão fica na
parede frontal e o R2 (pull-up) e o C3 (filtro) na placa auxiliar. Rabicho de
2 fios de ~15 cm com JST-XH de 2 vias (M7): cabo pré-crimpado soldado nos dois
terminais do contato NA, isolado com termorretrátil Ø 4 mm (E9), e header macho
na borda direita da placa auxiliar, ao lado do header do LED. No arranjo 3D o
percurso é de ~45 mm para a esquerda, ~8 mm para trás e ~23 mm para baixo
(~76 mm). Continua em aberto, para o profissional habilitado, ligar ou não o
corpo metálico do botão ao PE.

**USB de painel (decidido em 08/10/2026).** O cabo extensor de painel (M8) já é
desconectável: o plugue micro-B sai do micro-USB do ESP32 com o fundo aberto,
então não leva conector extra. O conector de painel fica na lateral esquerda
(y = 37,5) e o micro-USB do ESP32 na ponta traseira da placa, com a boca
voltada para a divisória. Percurso no arranjo 3D de ~10 cm (por cima do ESP32,
~49 mm em X, descendo ~14 mm e voltando ao plugue por trás); cabo de 20 a 30 cm
dá folga para baixar o fundo e soltar o plugue. Atrás do micro-USB sobram
~29 mm até a divisória — um plugue reto e a curva do cabo ficam justos nesse
espaço; conferir na montagem e, se não couber, usar plugue micro-B em 90°. O
corpo do conector de painel define o `recorte_usb` (ainda placeholder): medir
o M8 antes de imprimir.

## Aberturas por face

Todas as aberturas respeitam duas margens: no mínimo 6 mm da linha de dobra
(deformação na viradeira) e no mínimo 25 mm das extremidades (zona das abas de
canto).

| Face | Abertura | Posição |
|---|---|---|
| Tampo | nenhuma | regra de derrame |
| Frontal | Janela de RF, 40 × 28 mm | x = 75 mm |
| Frontal | LED RGB, Ø 5 mm | x = 150 mm |
| Frontal | Botão, Ø 12 mm | x = 195 mm |
| Traseira | Prensa-cabo PG9, Ø 15 mm | x = 70 mm |
| Traseira | Tomada J1, 45,5 × 23 mm | x = 185 mm |
| Lateral esquerda | 4 rasgos de 25 × 3 mm | 15 mm da borda inferior |
| Lateral esquerda | Recorte do USB de painel | y = 165 mm da traseira |
| Lateral direita | 5 rasgos de 25 × 3 mm | 15 mm da borda inferior |

Centros das aberturas frontais e traseiras a 22 mm do tampo.

A assimetria de rasgos entre as laterais é proposital: o recorte do USB ocupa a
posição de um rasgo na esquerda. Não corrigir.

## Decisões específicas e seus motivos

**Tomada J1 girada 90°.** O módulo 2P+T do sistema modular mede 45 × 22,5 mm com
~41 mm de profundidade. Um recorte de 45 mm numa saia de 45 mm não deixa
material. Girado, o recorte fica com 23 mm de altura e sobram ~10 mm de chapa
acima e abaixo. O plugue NBR 14136 é de corpo redondo, então girar não muda nada
visualmente; só o cabo sai de lado.

**Prensa-cabo PG9 em vez de passa-fio ou conector C14.** O prensa-cabo entrega
alívio de tração normalizado, que é o item que a inspeção elétrica procura, e faz
o menor recorte dos três numa saia que já perdeu 45,5 × 23 mm para a tomada. O
C14 daria cabo destacável, mas abriria um segundo retângulo grande na mesma saia
e mudaria o componente P1 no esquemático.

**Porta-fusível em linha, de corpo fechado, preso por abraçadeira.** Nenhum furo
adicional em chapa nenhuma. Interno, portanto a troca exige abrir o fundo — razão
a mais para acertar o valor do fusível.

**ESP32 com eixo longo no sentido frente-fundo**, antena encostada na janela de
RF da saia frontal, com ~5 mm de folga e nenhum metal na frente dela. O USB fica
apontando para a divisória e chega à saia lateral por um cabo de painel. Esse
cabo é o que desacopla a posição do conector da posição da placa: sem ele, USB
acessível e Wi-Fi decente seriam mutuamente exclusivos, porque no DevKit V1 a
antena e o micro-USB ficam em extremidades opostas.

**Estratégia térmica: pés mais rasgos laterais.** A fonte de calor está em cima e
o topo é fechado, então não existe efeito chaminé. Os rasgos e os pés impedem que
a caixa vire um forno selado e deixam o fundo trocar calor com o vão de ar. O
gargalo real é a condução pelo contato do tampo com a base da cafeteira, e isso
depende de medição.

**Largura de 3 mm nos rasgos** bloqueia dedo, não bloqueia arame fino. Bornes com
tampa na faixa de rede deixam de ser recomendação e passam a ser obrigatórios.

**Lábio de contenção de derrame: descartado por geometria.** As quatro bordas do
tampo já estão ocupadas pelas dobras das saias; não sobra aresta livre para uma
aba para cima. Um degrau embutido exigiria repuxo com matriz, que é outro
processo. O tratamento do derrame fica sendo a ausência de aberturas no tampo.

## Parâmetros do modelo

Os quatro primeiros são placeholders arbitrados. São eles que o revisor da
empresa vai corrigir, e é por isso que toda a geometria precisa depender deles por
expressão, nunca por número digitado.

```
espessura         1.2 mm     arbitrado
raio_dobra        1.2 mm     arbitrado
fator_k           0.40       arbitrado (ANSI)
material          inox austenítico   a confirmar

pegada_x          260 mm
pegada_y          210 mm
altura_externa    45 mm
altura_livre      41.4 mm
aba_fundo         12 mm
aba_canto         20 mm
recuo_aba         espessura + 0.3
alivio_canto      raio_dobra + espessura

pe_altura         10 mm
apoio_tipo        trilho | coxim | nenhum
apoio_altura      0 .. 5 mm
elevacao_total    altura_externa + pe_altura + apoio_altura

faixa_rede        120 mm
divisoria         2 a 3 mm
faixa_baixa       84 mm

rasgo             25 x 3 mm
rasgo_altura      15 mm da borda inferior
rasgo_margem      >= 6 mm da dobra, >= 25 mm das extremidades

janela_rf         40 x 28 mm, x=75
furo_led          5 mm, x=150
furo_botao        12 mm, x=195
prensa_cabo       PG9, Ø15 mm, x=70
tomada_j1         45.5 x 23 mm, x=185
usb_recorte       paramétrico, y=165 na lateral esquerda
furo_fixacao      3.2 mm (M3)
furo_porca_rebite ~4.5 mm, a confirmar
```

## Divergências a corrigir fora deste documento

| Onde | O quê |
|---|---|
| Esquemático KiCad | Valor de F1 de 10 A para 8 A |
| Especificação §2.1 | "Base de aço" passa a pedestal em inox, com a cafeteira apoiada em cima |
| Especificação §4.1 | Fonte 5 V já resolvida (HLK-PM01); a tabela ainda dá as duas opções |
| Especificação §4.5 e §9 | Isolamento galvânico por optoacoplador é falso com o jumper JD-VCC; já registrado antes desta sessão |

## Lista de verificação

Nenhum item abaixo é decisão. São medições, consultas ou ensaios.

### Medição no componente, depois da compra

| # | Item |
|---|---|
| 1 | Fixação do módulo de tomada em chapa de 1,2 mm: as garras travam no aço, ou exigem o suporte plástico atrás? Alternativas: suporte parafusado, parafuso M3 nas abas do módulo, cantoneira de retenção |
| 2 | Pegada real da base da cafeteira. O catálogo dá 257 × 198 mm, que é caixa envolvente e inclui a alça da jarra |
| 2b | A cafeteira tem pés próprios? Quantos, que altura, em que posições |
| 2c | Posições dos pés, para alinhar coxins caso seja esse o caminho |
| 3 | Posição da placa aquecedora na base, para afastar o HLK-PM01 da projeção dela |
| 4 | Dimensões reais do DevKit V1 de 30 pinos e do módulo de relé. Os valores no modelo são nominais de mercado |
| 5 | Diâmetro real do botão de painel e do LED, contra os furos de 12 mm e 5 mm |
| 14 | Faixa de aperto do PG9 comprado contra o diâmetro externo real do cabo. Nominal 4 a 8 mm |
| 16 | Flange e recorte do conector de painel micro-USB. Variam bastante entre modelos |
| 17 | Diâmetro de furo da porca-rebite M3 para chapa de 1,2 mm. Nominal ~4,5 mm |

### Consulta à empresa

| # | Item |
|---|---|
| 6 | Espessura disponível, raio mínimo de dobra e fator K da ferramenta. São os três que invalidam a planificação se estiverem errados |
| 7 | Formato de arquivo para o revisor: STEP, DXF da planificação, desenho 2D cotado ou o FCStd |
| 8 | Rigidez: 1,2 mm com 2,9 kg num vão de 260 mm basta, já com a aba de retorno de 12 mm? Levar a saia frontal com os recortes desenhados, não a saia lisa |
| 9 | Disponibilidade de rebite ou parafuso de inox. Alumínio em inox forma par galvânico, e derrame de café é rotina aqui |

### Ensaio de bancada

| # | Item |
|---|---|
| 10 | Temperatura da base da cafeteira após um ciclo completo. Não existe publicado, dimensiona toda a estratégia térmica e vira resultado citável na seção 4 do artigo |
| 11 | Atenuação de Wi-Fi com o ESP32 na caixa e a cafeteira em cima, para validar a janela de RF |
| 12 | Reset do ESP32 no acionamento do relé, para validar C1 e C2 na faixa de baixa tensão |

### Componentes a especificar

| # | Item |
|---|---|
| 13 | Isolamento térmico sob o tampo. Depende do 10. Verificar classe de temperatura e de inflamabilidade; comparar espuma injetada contra placa pré-cortada sobre falso teto. Custo geométrico: falso teto como peça adicional e ~12 mm de altura interna |
| 15 | Porta-fusível em linha fechado, 250 V, 5 × 20 mm. Fusível 8 A cerâmico; verificar capacidade de interrupção na folha de dados. Vidro tem capacidade baixa demais para proteção de rede |

---

## Atualização — impressão 3D (08/09/2026, issue #116)

**Pedido da issue:** reformular a mecânica para ser impressa (FDM), no lugar
de chapa dobrada, endereçando dobra, fixação, tolerância de parede,
ventilação e resistência mecânica sob a carga de operação.

**Decisão de arquitetura.** A Peça 1 deixa de ser 8 dobras + 4 abas de canto
e passa a ser **um sólido único impresso**: tampo + 4 paredes + flange
interna contínua na base — os 4 cantos já nascem fechados, sem fator K, sem
linha neutra, sem planificação. A Peça 2 continua um fundo plano removível,
parafusado por baixo, mesma lógica de manutenção da versão em chapa (abre
para trocar o fusível). Pegada (260 × 210 mm), altura externa (45 mm) e
arranjo interno (`mechanical/params/componentes_3d.csv`, mesmos 14
componentes de `componentes.csv`) foram preservados.

**Parede: 2,4 mm** (3 perímetros de bico 0,4 mm), contra 1,2 mm da chapa.
Motivo: numa peça impressa a parede é estrutura primária (não um invólucro
dobrado sobre si mesmo com abas de reforço) — 1,2 mm isolado tende a
delaminar ou flexionar sob os ~2,9 kg do conjunto cafeteira + água. 2,4 mm é
o mínimo prático recomendado nas referências de projeto para FDM consultadas
(regra geral de 3 perímetros como piso estrutural — inferência de projeto,
não normativa específica de eletrodoméstico). A altura interna livre cai de
41,4 mm (chapa) para 40,2 mm.

**Fixação Peça 1 / Peça 2: insert térmico rosqueado M3** (Ø furo 4,0 mm,
profundidade 6 mm, fundido a quente em 8 bosses da flange, Ø 9 mm), no lugar
da porca-rebite da chapa. Decisão e alternativas descartadas:
- **Parafuso auto-atarraxante direto no PETG:** descartado. A rosca em
  plástico degrada em poucas desmontagens, e o fundo abre rotineiramente
  para trocar o fusível (item 15 da lista de verificação) — não é uma
  junta que se abre uma vez só.
- **Porca comum presa por atrito/geometria:** descartado por não ter o
  mesmo travamento confiável de um insert fundido, e por exigir bolso extra
  na peça para a porca não girar.
- **Insert térmico M3:** mantido. Mesma lógica de montagem da chapa
  (parafuso entra por baixo, na Peça 2, e rosqueia no insert da Peça 1) —
  menor mudança de processo de montagem, rosca durável em plástico.
- Não há mais parafuso de canto: a peça impressa já nasce fechada nos 4
  cantos, então os 8 parafusos M3 de canto da chapa deixam de existir. Só
  restam os 8 parafusos de fixação do fundo.

**Ventilação e aberturas:** todo o catálogo de `mechanical/FUROS.md`
(janela de RF, LED, botão, prensa-cabo PG9, tomada J1, recorte USB, 9 rasgos
de ventilação) foi recriado 1:1 nas mesmas coordenadas (x, y, z), só a
espessura de parede atravessada mudou (2,4 mm em vez de 1,2 mm). Ver
`mechanical/scripts/build_peca1_3d.py` e a nota "Variante impressa (FDM)" no
próprio `FUROS.md`.

**Material: PETG, premissa desta issue, NÃO validado por ensaio.** Motivo:
PETG tem temperatura de deflexão térmica (HDT) mais alta que PLA (relevante
porque a cafeteira apoia diretamente no tampo) e é mais fácil de imprimir e
menos frágil que ABS. Esta é uma **inferência de engenharia geral**, não uma
confirmação — o item 10 da lista de verificação (temperatura da base da
cafeteira após um ciclo completo) segue pendente e é o que valida ou
invalida a escolha. Se o ensaio mostrar temperatura mais alta que a faixa
segura de HDT do PETG (~70 °C sob carga), reavaliar para ABS ou PC-blend.
Densidade usada nos scripts (`_env3d.DENSIDADE_PETG`) só para estimar massa
em **sólido cheio** — o infill real do fatiador fica abaixo disso.

**Resistência mecânica: estimativa analítica, não ensaio.** O tampo foi
tratado como uma placa retangular simplesmente apoiada nas 4 paredes (pior
caso realista), carga uniforme distribuída, fórmula de flecha máxima de placa
retangular (Roark's Formulas for Stress and Strain). Memória de cálculo em
`mechanical/scripts/_env3d.deflexao_tampo_mm`, validada por
`check_peca1_3d.py`. **Não substitui o ensaio de bancada** (item 8 adaptado:
imprimir o protótipo e testar com a carga real por semanas — a fluência não
aparece num teste curto).

**Audit da carga de 3 kg e reforço (revisão do modelo inicial).** O modelo
como entregue no PR #118 só checava a flecha **elástica** sob 2,9 kg e
passava raspando (0,57 mm vs. 0,70 mm). Dois furos:

1. **Fluência ignorada.** PETG sob carga contínua + calor irradiado pela base
   da cafeteira deforma 3–4× a flecha elástica ao longo de meses. Com
   `fator_fluencia = 4` e a carga de projeto `carga_operacao = 3,0 kgf` (o
   pedido explícito, não 2,9), o tampo **liso** dá flecha de longo prazo
   ≈ **2,4 mm** — estoura o `L/300`.
2. **Sem caminho de carga definido.** A massa ia do tampo às paredes por
   flexão, e das paredes ao fundo/pés por um caminho indireto.

**Reforço adicionado** (paramétrico, `parametros_3d.csv`; `coluna_qtd = 0` +
`nervura_transversal = 0` revertem ao modelo do #118):

- **4 colunas de canto** (`coluna_lado` 12 mm) do tampo ao plano do fundo —
  caminho de carga vertical direto, e travam o corpo contra racking.
- **Nervura perimetral** sob o tampo (`nervura_h` 6, `nervura_w` 3 mm) —
  enrijece a borda do tampo e o topo das paredes.
- **Nervura transversal** na linha da divisória — divide o vão do tampo em
  dois painéis: vão efetivo 210 → **118 mm**, flecha ÷ ~10.
- **Assentos de pé** coaxiais com as colunas na Peça 2 — fecham o caminho
  tampo → coluna → fundo → pé → bancada.

Custo: `altura_externa` cresce de 45 para **53 mm** (banda de nervura sob o
tampo; a cavidade útil de 40,2 mm e o arranjo interno descem juntos, sem
mudança de folgas — `componentes_3d.csv`). Elevação total ~66 mm.

Resultado (`check_peca1_3d.py`): flecha de longo prazo **com** reforço
≈ **0,24 mm** < `L/300` = 0,70 mm; nenhuma nervura/coluna colide com os 14
volumes internos (folga mínima 2,1 mm). **Continua estimativa, não ensaio** —
`fator_fluencia` é arbitrado; o ensaio de fluência de semanas é o que
confirma, e se der pior sobe-se `nervura_h`/`parede` sem retrabalho de
geometria.

**Novo entregável: STL.** `mechanical/scripts/export_stl.py` exporta
`peca1_3d.stl` e `peca2_3d.stl` (tolerância linear 0,1 mm), além do STEP —
requisito explícito da issue #116 para envio ao fatiador.

**Validação executada** (todos os scripts abaixo verdes via `freecadcmd`,
sem interferência entre Peça 1/Peça 2 nem com os 14 volumes do arranjo
interno): `build_peca1_3d.py`, `build_peca2_3d.py`, `check_peca1_3d.py`,
`check_peca2_3d.py`, `check_montagem_3d.py`, `build_arranjo_3d.py`,
`check_arranjo_3d.py`, `export_step_3d.py`, `export_stl.py`. O pipeline em
chapa (não renomeado, mantido por compatibilidade histórica) continua verde
e não foi alterado.

**O que fica pendente** (mesma natureza do que já estava pendente na versão
em chapa — medição, ensaio ou consulta, não decisão de arquitetura):
- Ensaio de temperatura da base da cafeteira (item 10) — confirma ou invalida
  a escolha de PETG.
- Ensaio de bancada com o protótipo impresso sob a carga real (equivalente
  ao item 8) — confirma ou invalida a estimativa analítica de flecha. Inclui
  um **ensaio de fluência de semanas** (carga de 3 kg + calor mantidos): é o
  que valida o `fator_fluencia` arbitrado no audit da carga.
- Medir os pés da cafeteira (itens 2b/2c) — se caírem no meio do vão do
  tampo em vez de perto dos cantos, alinhar o reforço (2ª nervura
  transversal) com onde a carga de fato entra.
- Insert térmico real comprado: confirmar `boss_d`/`insert_furo`/
  `insert_prof` contra o datasheet do insert específico (os valores atuais
  são nominais de M3×5,7, comuns no mercado).
- Itens 1 a 5, 13 a 17 da lista de verificação abaixo continuam válidos
  (dimensões reais de componentes, tomada, fusível, isolamento térmico) —
  são medições/consultas independentes da tecnologia de fabricação.

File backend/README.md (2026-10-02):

# cafey-backend

API do Cafey (Spring Boot / Kotlin). Há dois modos de rodar em desenvolvimento.

## Modo 1 — banco no Compose, API no host (`bootRun`)

Modo original, útil para depurar/rodar a API direto na IDE.

```bash
cd backend
docker compose up -d db
cd cafey-backend
./gradlew bootRun
```

A API sobe em `http://localhost:8080`, conectando ao Postgres publicado em `localhost:5432`
(credenciais padrão em `application.yml`: `cafey_user` / `cafey_password` / banco `cafey_db`).

## Modo 2 — stack completa via Compose (banco + API)

```bash
cd backend
docker compose up
```

Sobe o Postgres (`db`) e a API (`app`), construída a partir do `Dockerfile` em `cafey-backend/`
(multi-stage: `eclipse-temurin:21-jdk` para `./gradlew bootJar`, depois `eclipse-temurin:21-jre`
para rodar o jar). Na primeira execução o Compose constrói a imagem automaticamente — não é preciso
rodar `docker build` à parte. Para forçar rebuild após alterar código: `docker compose up --build`.

O serviço `app` espera o `db` ficar saudável (`depends_on: condition: service_healthy`) antes de
subir; o Flyway aplica as migrations no boot (`ddl-auto: validate`).

### Por que Dockerfile e não `bootBuildImage`

O plugin do Spring Boot inclui `bootBuildImage` (Cloud Native Buildpacks, sem Dockerfile). Foi
avaliado primeiro, mas Buildpacks não é um backend de build suportado nativamente pelo `docker
compose build`/`up --build`: seria preciso rodar `./gradlew bootBuildImage` manualmente antes de
`docker compose up`, o que reintroduz o passo manual no host que a issue #149 pedia para eliminar.
Um `Dockerfile` multi-stage permite que `docker compose up` construa a imagem sozinho.

### Variáveis de ambiente

Nenhuma credencial ou chave fica embutida na imagem — todas entram via variável de ambiente no
`compose.yaml` (com defaults de desenvolvimento quando ausentes):

| Variável | Uso | Default (dev) |
|---|---|---|
| `CAFEY_DB_USERNAME` / `CAFEY_DB_PASSWORD` / `CAFEY_DB_NAME` | credenciais do Postgres (`db` e `app`) | `cafey_user` / `cafey_password` / `cafey_db` |
| `CAFEY_JWT_PRIVATE_KEY` / `CAFEY_JWT_PUBLIC_KEY` | par de chaves RSA (PKCS#8/X.509, Base64 ou PEM) para assinar os JWT emitidos em `/auth` | vazio — gera par efêmero (dev/teste); **obrigatório com perfil `prod` ativo**, senão o boot falha |
| `CAFEY_CORS_ALLOWED_ORIGINS` | origem(ns), separadas por vírgula, autorizadas a chamar a API a partir do app Web | `http://localhost:8081` |
| `CAFEY_MAIL_FROM` / `CAFEY_MAIL_RESET_PASSWORD_URL` | remetente e URL da página de redefinição de senha (`/redefinir-senha.html`, servida pelo backend) usados no e-mail de recuperação | `Cafey <nao-responda@cafey.local>` / `http://localhost:8080/redefinir-senha.html` |
| `CAFEY_MAIL_SMTP_HOST` / `CAFEY_MAIL_SMTP_PORT` / `CAFEY_MAIL_SMTP_USERNAME` / `CAFEY_MAIL_SMTP_PASSWORD` | SMTP do AWS SES (`email-smtp.<região>.amazonaws.com`, credenciais SMTP do SES) — **só perfil `prod`**, propagadas por `compose.prod.yaml` | vazio / `587` / vazio / vazio — fora de `prod` o e-mail só é logado (`LogEmailSenderService`) |

Para sobrescrever localmente sem editar `compose.yaml`, crie um `backend/.env` (não versionado) com
as variáveis acima — o Compose o carrega automaticamente.

> **Resolvido em 2026-09-14 (issue #157):** o app Web publicado no Vercel
> (`https://cafey-web.vercel.app`) aponta para o backend remoto (`BACKEND_BASE_URL` no workflow
> de deploy) e `CAFEY_CORS_ALLOWED_ORIGINS` em produção já inclui essa origem — integração ponta a
> ponta validada (CORS, deploy do webApp e chamadas à API).

Certificados do AWS IoT Core (`aws.iot.certificate-path` / `private-key-path` / `root-ca-path`) são
montados via volume em produção (`backend/compose.prod.yaml`, bind mount de
`/opt/cafey/secrets:/run/secrets:ro`) com as properties apontadas pelas variáveis
`AWS_IOT_CERTIFICATE_PATH`/`AWS_IOT_PRIVATE_KEY_PATH`/`AWS_IOT_ROOT_CA_PATH` — o bean
correspondente só é ativado (`@ConditionalOnProperty`) se esses paths estiverem configurados; em
dev, a ausência não impede o boot (MQTT fica desabilitado). Ativado em produção desde 2026-09-14 —
ver `docs/docs_arquitetura/aws-iot-core-provisioning.md`.

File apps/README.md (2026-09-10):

# Caféy — apps

Projeto Kotlin Multiplatform (KMP) dos clientes Caféy: Android, Desktop (JVM) e Web (Kotlin/Wasm).
Build Gradle independente do backend (`backend/cafey-backend`), com wrapper próprio.

Sem target iOS: o ambiente de desenvolvimento é Windows e o CI roda em `ubuntu-latest`, onde o
target iOS não compila.

## Módulos

- `shared` — modelos de domínio, cliente HTTP (Ktor), autenticação e o design system Caféy
  (`br.com.tavaressan.cafey.shared.ui.theme`), compartilhados pelos três clientes. Nenhuma regra de
  negócio mora na UI (spec §2.3).
- `androidApp` — cliente Android.
- `desktopApp` — cliente Desktop (JVM, Compose Desktop).
- `webApp` — cliente Web (Kotlin/Wasm, Compose Multiplatform).

## Rodando cada target

Todos os comandos a seguir rodam a partir de `apps/`.

### Android

Requer Android SDK instalado (`sdk.dir` em `apps/local.properties`, não versionado).

```bash
./gradlew :androidApp:assembleDebug
# instala num dispositivo/emulador conectado:
./gradlew :androidApp:installDebug
```

### Desktop

```bash
./gradlew :desktopApp:run
```

### Web

```bash
./gradlew :webApp:wasmJsBrowserDevelopmentRun
```

Abre um servidor de desenvolvimento local servindo o Compose compilado para Wasm.

## Build completo (gate de CI)

```bash
./gradlew build
```

Compila os três targets e roda os testes de `shared` (`commonTest`).

## Design system

`shared/src/commonMain/kotlin/br/com/tavaressan/cafey/shared/ui/theme` traduz
`docs/docs_interface/prototype/assets/cafey.css` para Compose: `CafeyColors`, `CafeyTypography` e
`CafeyShapes`, expostos via o composable `CafeyTheme`. As fontes (Space Grotesk, Instrument Sans,
JetBrains Mono — SIL OFL) estão empacotadas em `shared/src/commonMain/composeResources/font`.

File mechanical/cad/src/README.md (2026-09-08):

# pedestal — modelos cadgen (build123d)

Réplica em `cadgen`/`build123d` da **variante impressa em 3D** do pedestal
(`mechanical/scripts/*_3d.py`, FreeCAD), para comparação independente de kernel.
Mesmo sistema de coordenadas do FreeCAD: canto em `(0,0)`, face superior do
tampo em `Z=0`, peça em `Z<0`.

| Script | Artefato | Descrição | Equivalente FreeCAD |
|---|---|---|---|
| `corpo.py` | `STEP/corpo.step` | Peça 1: tampo + paredes + flange + bosses + reforço + aberturas | `build_peca1_3d.py` |
| `tampa.py` | `STEP/tampa.step` | Peça 2: fundo + furos M3 + cantoneiras + assentos de pé | `build_peca2_3d.py` |
| `divisoria.py` | `STEP/divisoria.step` | Divisória de policarbonato + rasgo de passa-fio | (parte de `build_arranjo_3d.py`) |
| `arranjo.py` | `STEP/arranjo.step` | Raiz: corpo + tampa + divisória + 13 volumes de referência | `build_arranjo_3d.py` |

`lib/params.py` transcreve `mechanical/params/parametros_3d.csv` +
`componentes_3d.csv` como constantes (o gate do cadgen não lê arquivos) —
**manter em sincronia à mão**. `lib/geometry.py` são os helpers (`cbox` ancora
no canto mínimo como o `Part::Box`; `insert_xy`/`column_xy`/`vent_grid`
espelham `_env3d`).

## Uso

```bash
# venv Python 3.11 (cadgen exige >= 3.11; o python do sistema é 3.10):
uv venv --python python3.11 .venv
uv pip install --python .venv/bin/python "cadgen[snapshot]==0.5.0"

.venv/bin/python src/arranjo.py                 # constrói o root e os 3 filhos
.venv/bin/python -m cadgen.cli step inspect validate STEP/arranjo.step
.venv/bin/python -m cadgen.cli step inspect interfere STEP/arranjo.step --tolerance 0.5
.venv/bin/python -m cadgen.cli step inspect diff STEP/corpo.step ../build/peca1_3d.step
```

`cadgen step snapshot` **não funciona** neste host (Playwright não suporta
Chromium em macOS 12) — revisão visual fica pelo CAD Viewer ou por outro host.

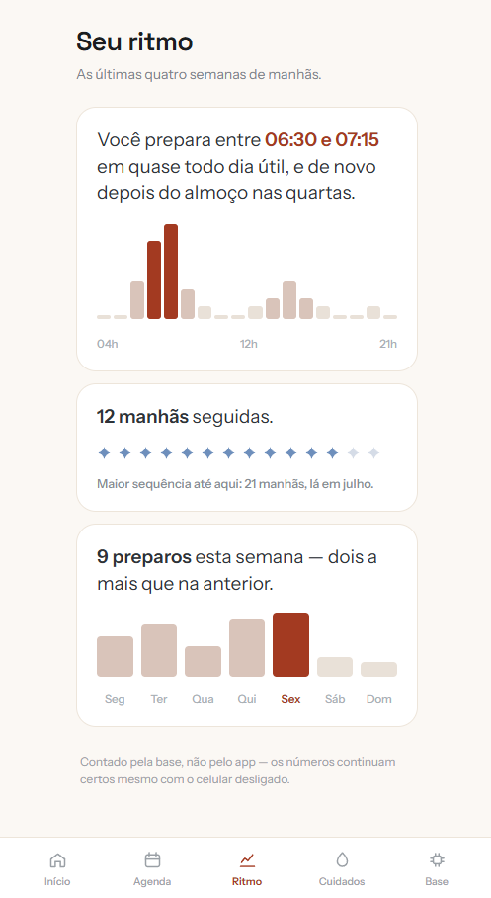
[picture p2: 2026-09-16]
docs/docs_artigo/imagens_artigo/rhythm_mobile_prototype.png

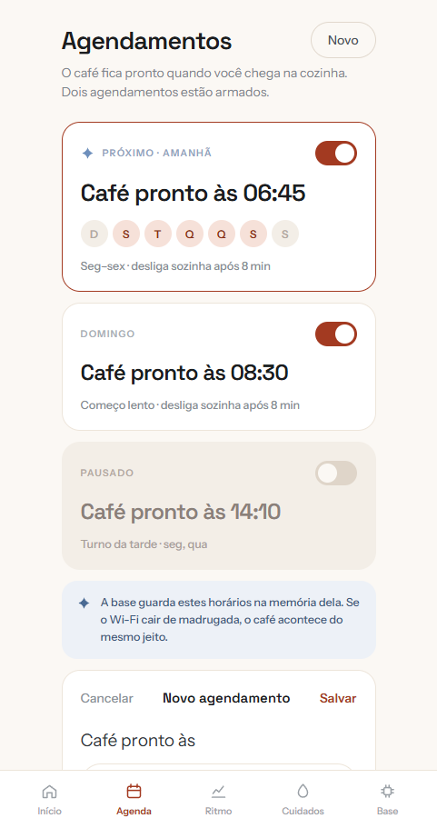
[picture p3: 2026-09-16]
docs/docs_artigo/imagens_artigo/schedule_mobile_prototype.png

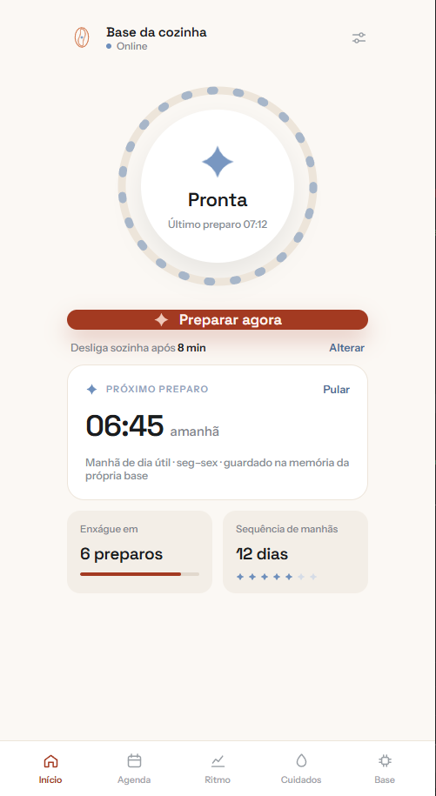
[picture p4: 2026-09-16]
docs/docs_artigo/imagens_artigo/home_mobile_prototype.png

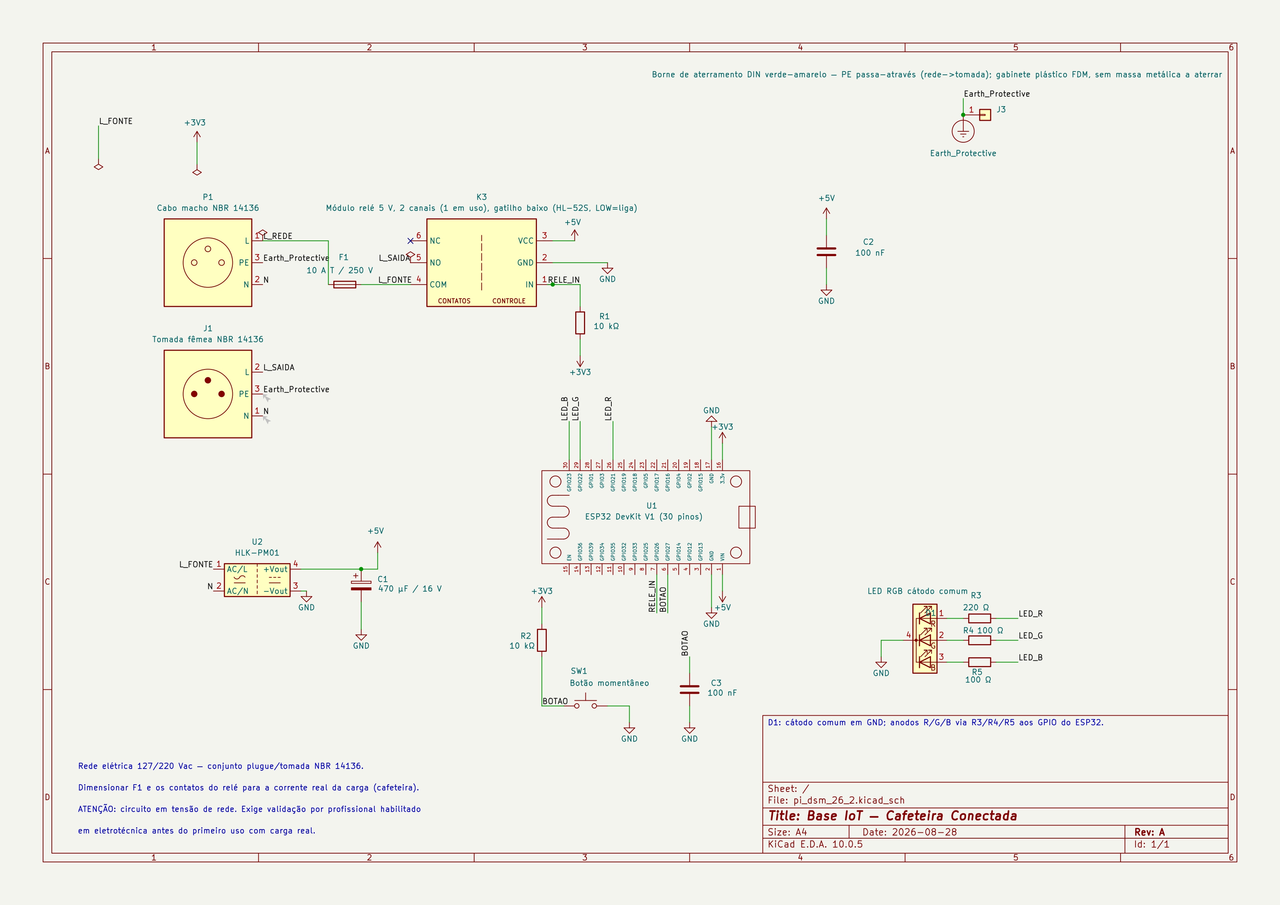
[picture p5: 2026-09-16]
docs/docs_artigo/imagens_artigo/pi_dsm_26_2_image.jpg

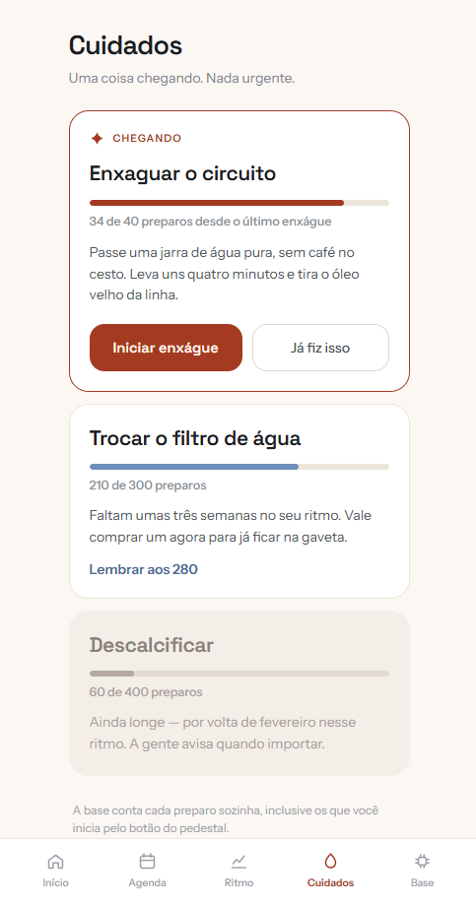
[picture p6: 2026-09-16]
docs/docs_artigo/imagens_artigo/care_mobile_prototype.png

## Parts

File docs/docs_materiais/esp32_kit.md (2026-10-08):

# Kit ESP32 Basic Starter Kit — Inventário e Referência Técnica

> Documento de referência do hardware disponível para o projeto **Cafeteira Conectada (Cafey)**.
> Fonte primária: manual `ESP32 Basic Starter Kit — V2.0.23.10.11` (137 páginas), fornecido com o kit.
> Unidades em posse: **2 kits idênticos**.

---

## 1. Identificação e escopo

| Item | Valor | Natureza |
|---|---|---|
| Nome no manual | ESP32 Basic Starter Kit | Fato (capa do manual) |
| Versão do manual | V2.0.23.10.11 | Fato (capa do manual) |
| Fabricante/distribuidor | LAFVIN | Inferência — não consta no texto do manual; identificação vem da embalagem física |
| Placa de referência | ESP32 DEVKIT V1 (DOIT), versão de **30 pinos** | Fato (p. 4–5) |
| Projetos guiados | 10 | Fato (sumário) |
| Quantidade de kits | 2 | Informado pelo usuário |

### Origem do inventário

A página **Packing List (p. 1/137) do PDF é apenas imagem, sem camada de texto** — a extração textual não a recupera. O inventário da §2 foi transcrito da **captura da página impressa**, fornecida em 2026-09-08. A lista é agora **fato documental**, não mais inferência.

---

## 2. Inventário oficial (Packing List, p. 1/137)

21 itens de linha. Quantidades transcritas literalmente da lista do fabricante.

| # | Componente | Qtd./kit | Total (2 kits) |
|---|---|---|---|
| 1 | ESP32 Development Board | 1 | 2 |
| 2 | Display OLED 0,96" (SSD1306, 128×64, I²C) | 1 | 2 |
| 3 | Protoboard 830 pontos (MB-102, tamanho completo) | 1 | 2 |
| 4 | Módulo de desvio de obstáculo (IR) | 1 | 2 |
| 5 | Módulo de resistor fotossensível (LDR) | 1 | 2 |
| 6 | Módulo DHT11 (temperatura e umidade) | 1 | 2 |
| 7 | Sensor de movimento PIR HC-SR501 | 1 | 2 |
| 8 | Potenciômetro 10 kΩ | 1 | 2 |
| 9 | Cabo micro-USB | 1 | 2 |
| 10 | **Resistor 220 Ω** | **30** | **60** |
| 11 | Buzzer passivo | 1 | 2 |
| 12 | Buzzer ativo | 1 | 2 |
| 13 | **Módulo relé 5 V, 2 canais** | 1 | 2 |
| 14 | Chave de botão (tactile switch) | 6 | 12 |
| 15 | Cabo DuPont F-M | 10 | 20 |
| 16 | Cabo DuPont F-F | 10 | 20 |
| 17 | Cabo DuPont M-M | 10 | 20 |
| 18 | LED vermelho 5 mm | 5 | 10 |
| 19 | LED amarelo 5 mm | 5 | 10 |
| 20 | LED verde 5 mm | 5 | 10 |
| 21 | **LED RGB (cátodo comum)** | 2 | 4 |

### 2.1 Achados críticos da lista

**A1 — Não há resistor de 10 kΩ no kit.** O único valor fornecido é 220 Ω (30 un.). Os Projetos 1 e 8 do próprio manual pedem `10k Ohm resistor` para o botão; o kit não o fornece. O potenciômetro de 10 kΩ (item 8) é um componente distinto e não substitui um resistor fixo em divisor de tensão.

> **Impacto no Cafey**: o net `BOTAO` do esquemático KiCad depende de um pull-up. Duas saídas, em ordem de simplicidade:
>
> 1. **Pull-up interno do ESP32** (`INPUT_PULLUP` / `gpio_pullup_en`) — elimina o componente, o custo e o ponto de solda. O ESP32 tem pull-ups internos em todos os GPIOs exceto 34–39. Solução mais simples, sem compra.
> 2. **Resistor externo de 10 kΩ** — exige aquisição, mas dá valor determinístico (o pull-up interno do ESP32 é especificado em faixa ampla, tipicamente dezenas de kΩ) e resistência a ruído em cabo longo.
>
> A decisão é do projeto; a alternativa mais simples fica sinalizada. Enquanto não for decidida, o protótipo de bancada pode usar o pull-up interno sem bloquear a Seção 4 do artigo.
>
> **Atualização (08/10/2026):** há resistores de 10 kΩ em estoque, fora do kit. A opção 2 deixa de exigir compra, e o R1 (pull-up do relé) e o R2 (pull-up do botão) do esquemático ficam cobertos.

**A2 — Dois módulos não cobertos pelo manual.** O módulo de desvio de obstáculo (IR) e o módulo de resistor fotossensível (LDR) constam na lista mas **não aparecem em nenhum dos 10 projetos** do manual. Não têm aplicação prevista no Cafey; ficam como reserva.

**A3 — Divergência D2 resolvida.** Não existe resistor de 200 Ω no kit. A menção a `2x 200 Ohm` no Projeto 5 é erro de redação do manual. Confirma a padronização de R4/R5 em 220 Ω já aplicada no `diagram.json` do Wokwi.

**A4 — Relé identificado como HL-52S V1.0.** A Packing List diz apenas "5V 2-Channel Relay Module". O **diagrama de pinagem do manual** (p. 94–96) mostra a serigrafia `HL-52S V1.0` / `2 relay module` — ver §4.6. Ressalva: trata-se da ilustração do manual, não de uma fotografia da unidade em posse; a correspondência entre a ilustração e a placa física ainda merece conferência visual rápida na bancada.

**A5 — Protoboard de 830 pontos.** Confirma o MB-102 de tamanho completo já adotado no `diagram.json` do Wokwi.

**A6 — LEDs discretos são coloridos, não genéricos.** 15 LEDs por kit (5 vermelhos, 5 amarelos, 5 verdes). Onde o manual diz "5mm LED", qualquer uma das três cores serve. Não há LED azul discreto — só dentro do RGB.

**A7 — Cabos M-M são o recurso mais escasso.** 10 por kit (20 no total) para montagem em protoboard. Uma bancada com relé + LED RGB + botão + alimentação consome boa parte disso. Os cabos F-M e F-F servem para módulos com pinos fêmea (relé, DHT11, PIR).

---

## 3. Placa ESP32 DEVKIT V1 (DOIT) — especificações

Todos os dados desta seção são **fato documental** (manual, p. 5–7).

| Característica | Valor |
|---|---|
| Núcleos | 2 (dual core) — Tensilica Xtensa LX6 32 bits |
| Clock | até 240 MHz |
| Wi-Fi | 2,4 GHz, até 150 Mbit/s |
| Bluetooth | BLE + Bluetooth clássico |
| RAM | 512 KB (SRAM 520 KB no chip; 448 KB ROM) |
| Pinos | 30 |
| Ponte USB↔UART | **CP2102** |
| Botões | RESET (rotulado EN) e BOOT |
| LEDs on-board | Azul no **GPIO 2**; vermelho indica alimentação |
| Interface | micro-USB (alimentação + gravação) |
| Corrente máx. por GPIO | **40 mA** (absoluto, conforme datasheet ESP32) |
| Sensor extra | Sensor Hall integrado |

### 3.1 Restrições de GPIO — crítico para o Cafey

**Nunca usar (flash SPI interna do ESP-WROOM-32):** GPIO 6, 7, 8, 9, 10, 11.

**Somente entrada (sem pull-up/pull-down internos):** GPIO 34, 35, 36, 39.

**Strapping pins** — estado no boot afeta a inicialização:

| GPIO | Requisito no boot |
|---|---|
| 0 | LOW para entrar em modo boot; emite PWM no boot; tem pull-up |
| 2 | Flutuante ou LOW para entrar em modo gravação |
| 4 | Strapping pin |
| 5 | HIGH durante o boot; emite PWM no boot |
| 12 | **LOW durante o boot** — o boot falha se estiver em HIGH |
| 15 | HIGH durante o boot; emite PWM no boot |

**Pinos que vão a HIGH ou emitem PWM no boot/reset:** GPIO 1, 3, 5, 6–11, 14, 15.

> **Implicação direta para o módulo de relé**: o pino de comando do relé **não deve** ser alocado em nenhum GPIO desta lista. Com o HL-52S sendo *active-low*, um pino que sobe para HIGH no boot é seguro (relé desenergizado); já um GPIO que emite PWM no boot causaria chaveamento espúrio. Combinar com a decisão de firmware `kRelayIdleLevel`.

**Livres e recomendados (OK como entrada e saída, sem efeito no boot):** GPIO 13, 16, 17, 18, 19, 21, 22, 23, 25, 26, 27, 32, 33.

### 3.2 Periféricos por pino

- **ADC**: 18 canais de 12 bits (0–4095 ↔ 0–3,3 V). Na DEVKIT V1 de 30 pinos, **15 disponíveis**.
  - ADC1: GPIO 32, 33, 34, 35, 36, 37, 38, 39
  - ADC2: GPIO 0, 2, 4, 12, 13, 14, 15, 25, 26, 27
  - **Restrição: ADC2 não funciona com Wi-Fi ativo.** Como o Cafey usa Wi-Fi permanentemente, qualquer leitura analógica futura deve ficar em ADC1.
  - Resposta **não linear** nos extremos (~0–0,1 V e ~3,2–3,3 V).
- **DAC** (8 bits): GPIO 25, 26.
- **I²C** (padrão Arduino): SDA = GPIO 21, SCL = GPIO 22. Qualquer pino pode ser remapeado via `Wire.begin(SDA, SCL)`.
- **SPI**: VSPI → MOSI 23, MISO 19, CLK 18, CS 5. HSPI → MOSI 13, MISO 12, CLK 14, CS 15.
- **PWM**: 16 canais independentes; qualquer pino de saída serve (GPIO 34–39 não).
- **Touch capacitivo** (10 canais): T0=4, T1=0, T2=2, T3=15, T4=13, T5=12, T6=14, T7=27, T8=33, T9=32.
- **RTC GPIO** (wake-up de deep sleep): 0, 2, 4, 12, 13, 14, 15, 25, 26, 27, 32, 33, 34, 35, 36, 39.
- **Interrupções**: todos os GPIOs.
- **EN**: enable do regulador 3,3 V, com pull-up. Ligar ao GND desliga o regulador (reset por botão externo).

---

## 4. Módulo de relé (Projeto 7) — leitura integral

Seção mais relevante do manual para o Cafey. Conteúdo é **fato documental** (p. 94–99).

### 4.1 Lado de alta tensão

Dois conectores de 3 bornes cada:

- **COM** — corrente a ser controlada (rede elétrica).
- **NC (normalmente fechado)** — COM e NC conectados por padrão; corrente flui até o ESP32 comandar a abertura.
- **NO (normalmente aberto)** — sem conexão por padrão; corrente flui apenas quando comandado.

### 4.2 Lado de baixa tensão

Dois conjuntos de pinos:

1. **VCC, GND, IN1, IN2** — alimentação lógica e comando dos dois canais.
2. **GND, VCC, JD-VCC** — alimentação do eletroímã.

### 4.3 Polaridade de acionamento

O manual afirma: *o relé é acionado quando a entrada cai abaixo de aproximadamente 2 V* — ou seja, **acionamento por nível baixo (active-low)**, coerente com a identificação do HL-52S. Tabela do manual:

| Configuração | Sinal HIGH | Sinal LOW |
|---|---|---|
| NC (normalmente fechado) | corrente flui | corrente não flui |
| NO (normalmente aberto) | corrente não flui | corrente flui |

> **Verificado em bancada (2026-09-08, teste §4.6.3): acionamento *active-low* confirmado — IN em nível LOW energiza o relé.** A afirmação deixa de ser inferência a partir do manual e passa a ser resultado experimental. Consequências imediatas:
>
> - **Esquemático KiCad**: a polaridade do net `RELE_IN` ainda está desenhada como *active-high*. Deve ser corrigida para *active-low*, eliminando a última divergência entre o esquemático e a `spec-cafeteira-conectada.md`.
> - **Firmware**: `kRelayActiveLevel = 0`, `kRelayIdleLevel = 1`; `init()` deve escrever o nível de repouso **HIGH** antes de configurar o pino como saída.
> - **Configuração de contatos**: usar **NO**, mantendo a cafeteira desligada por padrão.

### 4.4 Jumper JD-VCC e isolação — ponto já registrado na spec

O manual é explícito:

- **Com o jumper VCC↔JD-VCC instalado**: o eletroímã é alimentado diretamente pelo pino de alimentação do ESP32, e *"o módulo de relé e os circuitos do ESP32 **não estão** fisicamente isolados entre si"*.
- **Sem o jumper**, alimentando JD-VCC por fonte independente: *"essa configuração isola fisicamente os relés do ESP32 através do optoacoplador embutido no módulo"*.

> Esta é a **fonte primária** que sustenta a correção pendente nos §4.5 e §9 da `spec-cafeteira-conectada.md`: com o jumper no lugar, o optoacoplador **não** provê isolação galvânica. A isolação restante é a rigidez dielétrica dos contatos do relé.

### 4.6 Pinagem física — HL-52S V1.0

O diagrama de pinagem do manual (p. 94–96) identifica a placa pela serigrafia: **`HL-52S V1.0`** na borda superior e **`2 relay module`** na inferior.

**Lado de alta tensão** — dois blocos de bornes de 3 vias, um por canal. Ordem em cada bloco, de cima para baixo:

| Posição | Borne |
|---|---|
| 1 | **NO** (normalmente aberto) |
| 2 | **COM** (comum) |
| 3 | **NC** (normalmente fechado) |

**Header de controle (4 vias)** — serigrafia `GndIn1In2Vcc`:

| Pino | Função |
|---|---|
| 1 | GND |
| 2 | **IN1** — canal inferior |
| 3 | **IN2** — canal superior |
| 4 | VCC (lógica, 5 V) |

**Header de alimentação da bobina (3 vias)** — serigrafia `JDVccVccGnd`:

| Pino | Função |
|---|---|
| 1 | **JD-VCC** — alimentação do eletroímã |
| 2 | VCC |
| 3 | GND |

O **jumper de fábrica ocupa as posições JD-VCC e VCC**, curto-circuitando as duas. É esse jumper que anula a função do optoacoplador (ver §4.4).

> **Nota sobre isolação no Cafey (inferência):** remover o jumper só produz isolação se JD-VCC receber uma fonte **independente** do rail que alimenta o ESP32. Na arquitetura atual, o HLK-PM01 alimenta ambos a partir do mesmo secundário — remover o jumper, nessa topologia, não cria isolação galvânica real. Isso é consistente com a redação corrigida da spec: a isolação efetiva vem da rigidez dielétrica dos contatos do relé.

---

### 4.5 Aviso de segurança do manual

O manual **substitui a carga de rede por LEDs de 5 mm** no experimento do Projeto 7, e recomenda desconectar tudo da rede durante a programação e a montagem. O Cafey vai além do escopo do manual ao comutar 127 V reais — o que reforça a necessidade da validação elétrica interna já prevista.

---

## 5. Toolchain documentada no manual

| Item | Valor |
|---|---|
| IDE | Arduino IDE (manual recomenda a linha **1.8.x** legada, por causa do plugin SPIFFS Uploader, ainda sem suporte na v2) |
| URL de Boards Manager | `https://raw.githubusercontent.com/espressif/arduino-esp32/gh-pages/package_esp32_index.json` |
| Pacote | "ESP32 by Espressif Systems" |
| Placa a selecionar | **ESP32 Dev Module** (ou *DOIT ESP32 DEVKIT V1*) |
| Driver USB | **CP210x USB to UART Bridge VCP** — obrigatório se a porta COM não aparecer |
| Baud rate do Serial Monitor | **115200** em todos os projetos |
| Sketch de teste | `File > Examples > WiFi (ESP32) > WiFiScan` |

> Observação: a recomendação de usar a Arduino IDE 1.8.x reflete o estado da ferramenta na data do manual (2023). Não confirmada contra fonte oficial atual — tratar como provisória. O Cafey usa ESP-IDF/PlatformIO, então esta seção serve apenas para testes rápidos de bancada com os componentes do kit.

### 5.1 Procedimento de recuperação de gravação

Se aparecer `A fatal error occurred: Failed to connect to ESP32: Timed out... Connecting...`:

1. Manter **BOOT** pressionado;
2. Clicar em **Upload** na IDE;
3. Soltar **BOOT** ao ver a mensagem `Connecting....`;
4. Após `Done uploading`, pressionar **EN** para reiniciar.

### 5.2 Bibliotecas exigidas pelos projetos

| Biblioteca | Projetos | Instalação indicada pelo manual |
|---|---|---|
| `WiFi.h` | 5, 6, 7, 8, 9 | Nativa do core ESP32 |
| `ESPAsyncWebServer` | 7, 8, 9 | ZIP manual (`Sketch > Include Library > Add .ZIP`) |
| `AsyncTCP` | 7, 8, 9 | ZIP manual — dependência da anterior |
| `DHT sensor library` | 9 | ZIP manual |
| `Adafruit Unified Sensor` | 9 | ZIP manual — dependência da anterior |
| `Adafruit_SSD1306` | 10 | Library Manager |
| `Adafruit_GFX` | 10 | Library Manager |

---

## 6. Mapa de pinos usado pelos projetos do manual

Útil como referência de bancada; **não** define a pinagem do Cafey.

| Projeto | Componente | GPIO |
|---|---|---|
| 1 | Push-button | 4 |
| 1 | LED | 5 |
| 2 | Potenciômetro (analógico) | 4 — ADC2_CH0 |
| 3 | LED (PWM) | 4 |
| 5 | LED 1 / LED 2 | 26 / 27 |
| 10 | OLED SDA / SCL | 21 / 22 (Vin em **3,3 V**) |

> Alerta: o Proj. 2 usa GPIO 4 (ADC2) para leitura analógica — combinação que **falha com Wi-Fi ativo**, contrariando a própria nota do manual na p. 14. Divergência interna do documento.

---

## 7. Divergências identificadas no manual

Registradas para não serem tratadas como verdade em decisões de projeto:

| # | Divergência | Páginas | Leitura adotada |
|---|---|---|---|
| D1 | Placa descrita como "30 pinos" na introdução e como "DOIT board with 36 pins" no Proj. 5 | 5 vs. 66 | **30 pinos** — corresponde à placa física |
| D2 | Resistor de 200 Ω no Proj. 5 vs. 220 Ω em todos os demais | 66 vs. 35/53/85/105 | **Resolvida** — o kit só contém 220 Ω (Packing List). Erro de redação do manual |
| D3 | Proj. 2 lê ADC2 (GPIO 4) sem ressalva, apesar do alerta "ADC2 não funciona com Wi-Fi" | 46 vs. 14 | Alerta prevalece; usar ADC1 quando houver Wi-Fi |
| D4 | Projetos 7 (relé) e 10 (OLED) não têm seção *Parts Required* | 94, 127 | **Resolvida** — ambos constam na Packing List |
| D5 | Projetos 1 e 8 exigem resistor de **10 kΩ**, que o kit não fornece | 35, 105 | Não executáveis como descritos. Usar pull-up interno do ESP32 ou adquirir o resistor (ver §2.1 A1) |
| D6 | Módulos IR de obstáculo e LDR constam na Packing List mas não são usados em nenhum dos 10 projetos | p. 1 | Componentes órfãos; sem documentação de uso no manual |

---

## 8. Aplicabilidade ao projeto Cafey

### 8.1 O que os 2 kits cobrem sem compra adicional

- **Protótipo de bancada do módulo de relé** (Seção 4 do artigo EnGeTec): ESP32 + módulo relé 5 V 2 canais + LED indicador + protoboard 830 pontos + cabos DuPont. Suficiente para o teste §4.6.3 (confirmação da polaridade *active-low*).
- **LED RGB de status**: 2 unidades cátodo comum por kit, com 30 resistores de 220 Ω disponíveis — cobre com folga os nets `LED_R/G/B`.
- **Botão físico local**: 6 chaves tácteis por kit para o net `BOTAO`. **Sem o resistor de pull-up** — ver §2.1 A1.
- **Bancada redundante**: o segundo kit permite manter uma montagem de referência íntegra enquanto a primeira é modificada, e é reserva imediata caso um ESP32 seja danificado nos testes com rede elétrica.
- **Instrumentação opcional**: DHT11 disponível se o projeto vier a monitorar temperatura ambiente ou da base da cafeteira — não previsto na arquitetura atual (conclusão de preparo é por temporizador, sem sensores).

### 8.2 O que os kits **não** cobrem

- **Resistor de 10 kΩ** — único item de baixo custo faltante para replicar os projetos do manual (§2.1 A1).
- Fonte AC-DC **HLK-PM01** (comutação da fase de rede).
- Bornes/conectores para 127 V, prensa-cabo PG9, cabo com plugue NBR 14136.
- Gabinete em aço inox, insertos M3, chapa-base.
- Cafeteira Britânia CP30 (carga de teste).

### 8.3 Pendências abertas

- [x] ~~Conferir a Packing List física e substituir a §2 por quantidades de fato~~ — concluído em 2026-09-08.
- [x] ~~Verificar se o kit inclui cabo micro-USB~~ — confirmado, 1 por kit.
- [ ] **Decidir o pull-up do net `BOTAO`**: interno do ESP32 (sem compra) ou resistor externo de 10 kΩ (compra). Ver §2.1 A1.
- [x] ~~Confirmar o modelo do módulo de relé~~ — **HL-52S V1.0**, conforme diagrama do manual (§4.6). Resta apenas conferir visualmente se a placa física traz a mesma serigrafia.
- [x] ~~Executar teste §4.6.3 de polaridade do relé~~ — concluído em 2026-09-08: **active-low confirmado**.
- [ ] **Corrigir a polaridade do net `RELE_IN` no esquemático KiCad** para *active-low* (era a última divergência aberta entre esquemático e spec).
- [ ] **Corrigir `relay.cpp`**: introduzir `kRelayActiveLevel`/`kRelayIdleLevel` e fazer `init()` escrever o nível de repouso antes de configurar o pino como saída.
- [ ] **Testar o comportamento do pino IN em alta impedância**: entre a energização da placa e a execução do `init()`, o GPIO do ESP32 fica como entrada flutuante. *Hipótese a verificar*: no HL-52S o IN é o cátodo do LED do optoacoplador, de modo que flutuante ⇒ sem corrente ⇒ relé desenergizado. Teste: alimentar o módulo com o IN desconectado e observar se o relé permanece aberto. Se não permanecer, é necessário um pull-up externo para VCC no IN.
- [ ] Verificar em qual GPIO o net `RELE_IN` está alocado no esquemático KiCad — evitar GPIO 1, 3, 5, 14, 15 (PWM/HIGH no boot; ver §3.1).

---

## 9. Procedência

| Campo | Valor |
|---|---|
| Documento-fonte | `ESP32_Basic_Starter_Kit_Tutorial.pdf`, 137 páginas |
| Versão do manual | V2.0.23.10.11 |
| Método de extração | Extração da camada de texto do PDF |
| Cobertura | Páginas 2–137 via camada de texto |
| Packing List (p. 1) | Sem camada de texto no PDF; transcrita de captura da página impressa |
| Data da extração | 2026-09-08 |
| Status | **Completo** para o conteúdo do manual. Pendências residuais em §8.3 dependem de inspeção do hardware físico, não do documento |

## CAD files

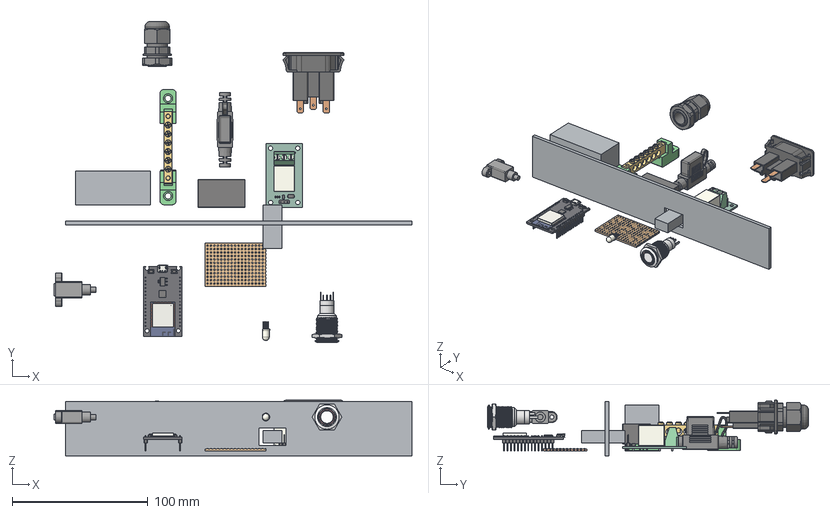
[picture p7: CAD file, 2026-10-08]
mechanical/arranjo_3d.step
263.6 x 236.6 x 41.1 mm
divisoria (policarbonato/acrilico)
esp32
placa_aux
led_rgb
botao
usb_painel
borne_rede
terra_j3
porta_fusivel
hlk_pm01
modulo_rele
prensa_cabo_corpo
tomada_j1_corpo
travessia_fios

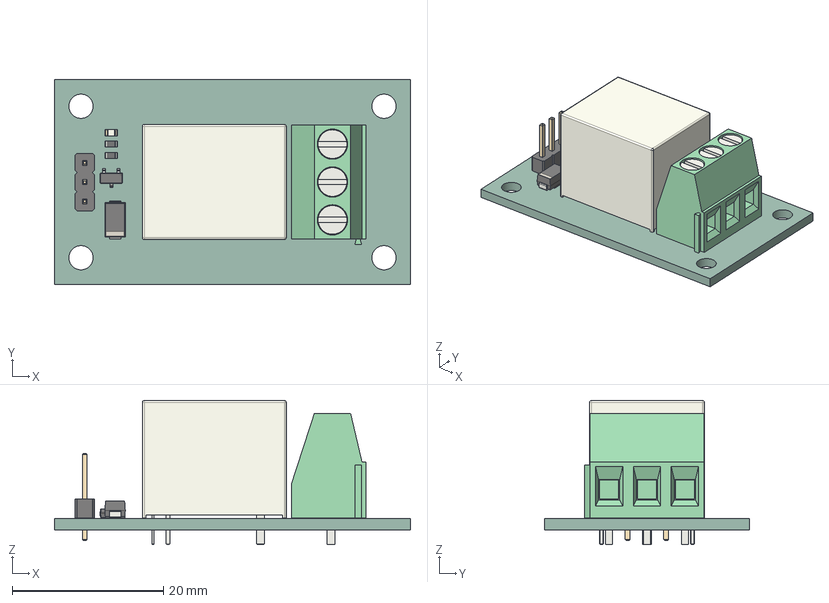
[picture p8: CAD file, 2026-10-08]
mechanical/models/modulo-rele-v3.step
47.0 x 27.0 x 19.0 mm

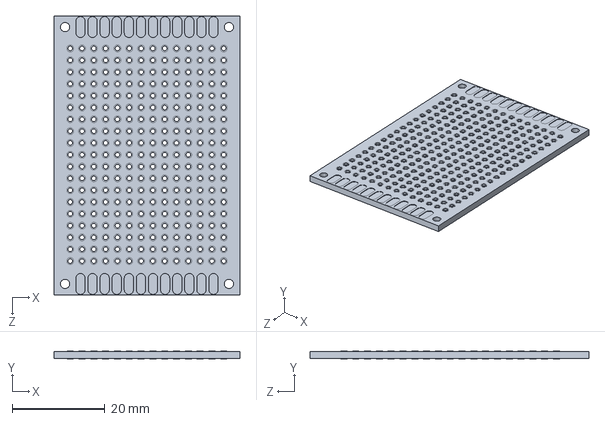
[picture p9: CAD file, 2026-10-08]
mechanical/models/placa-ilhada-60x40.step
40.0 x 1.70 x 60.0 mm

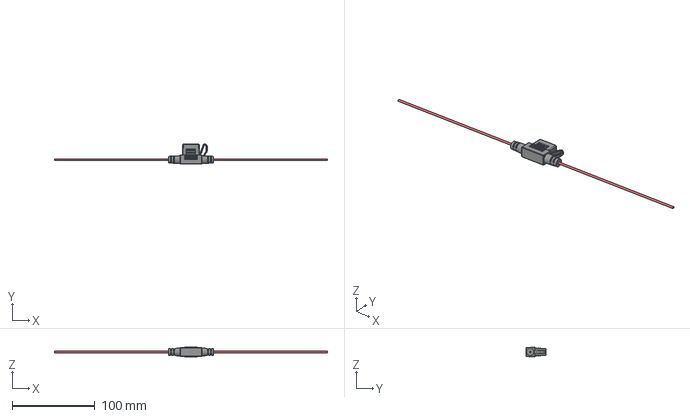
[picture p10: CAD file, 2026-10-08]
mechanical/models/porta-fusivel-inline.step
330.8 x 24.6 x 11.9 mm

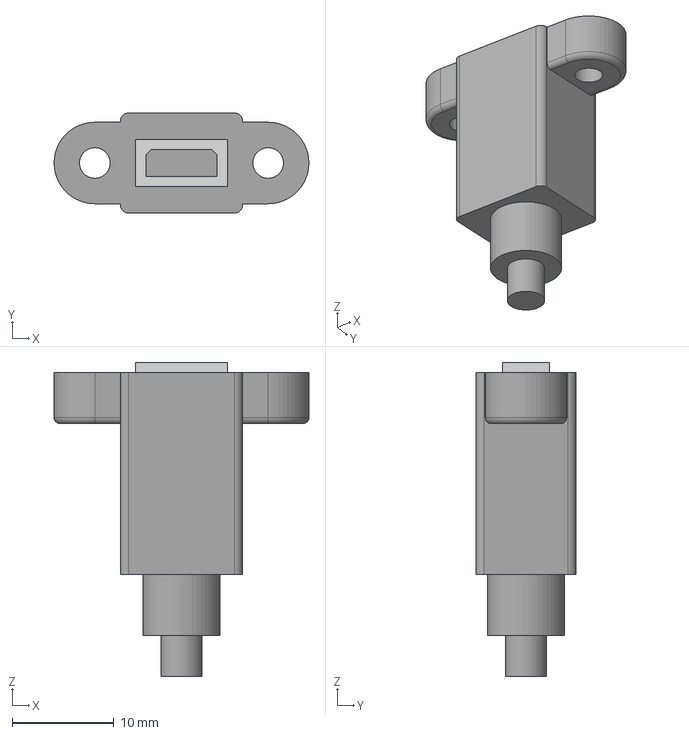
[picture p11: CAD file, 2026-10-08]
mechanical/models/adafruit-3258-microusb-painel.step
25.0 x 9.80 x 30.8 mm

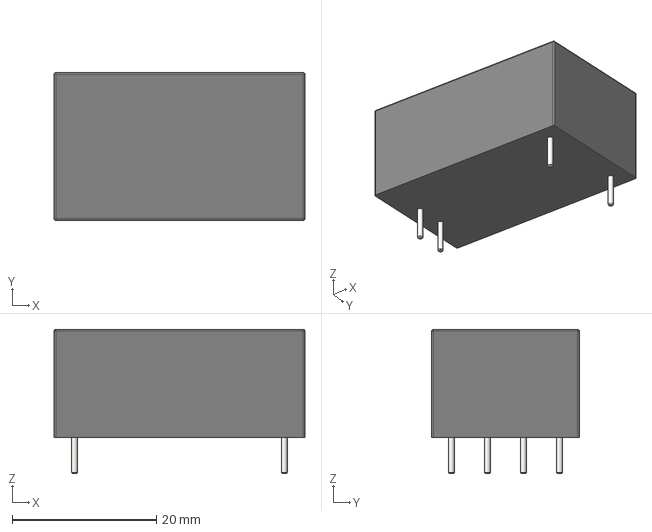
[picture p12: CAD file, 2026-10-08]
mechanical/models/hlk-pmxx.step
34.8 x 20.5 x 20.0 mm

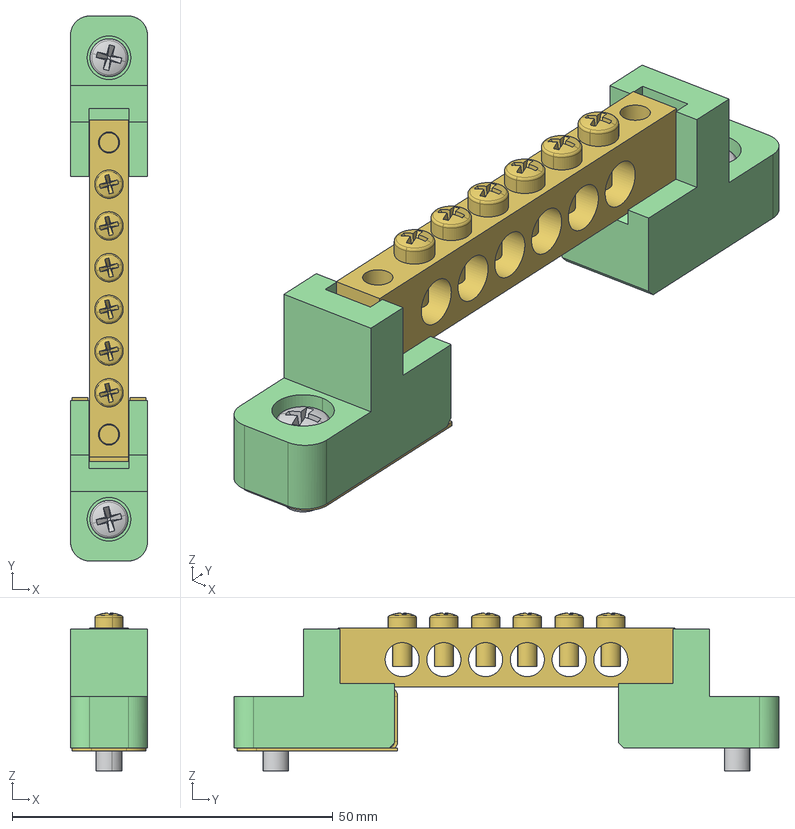
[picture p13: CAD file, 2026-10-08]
mechanical/models/barramento-terra-lukma-6p.iges
12.0 x 84.9 x 24.6 mm

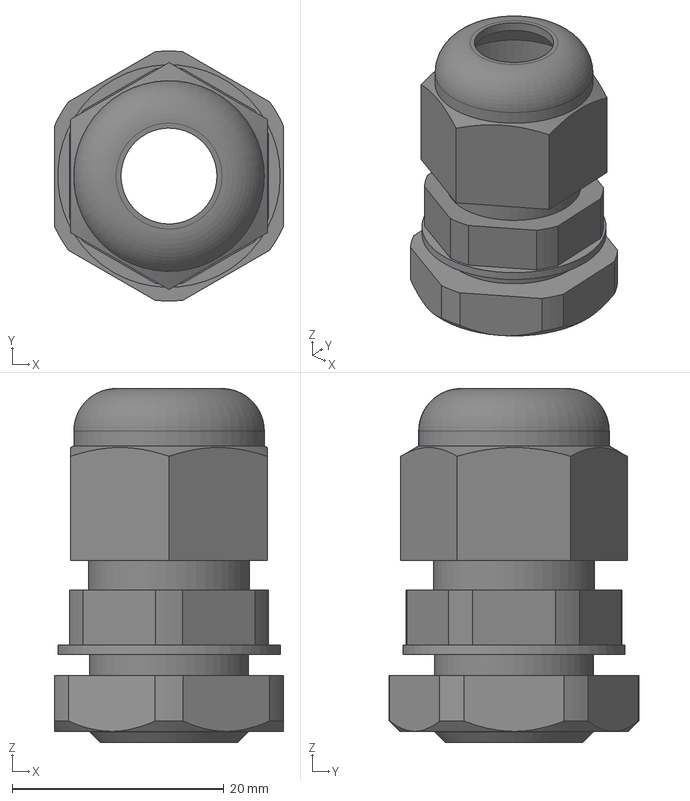
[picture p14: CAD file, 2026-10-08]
mechanical/models/PG9 Gland.step
21.6 x 23.6 x 33.4 mm

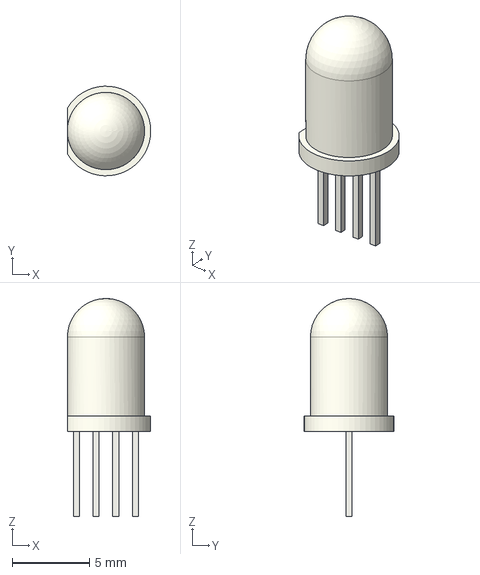
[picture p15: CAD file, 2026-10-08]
mechanical/models/led-5mm-rgb.step
5.40 x 5.79 x 14.1 mm

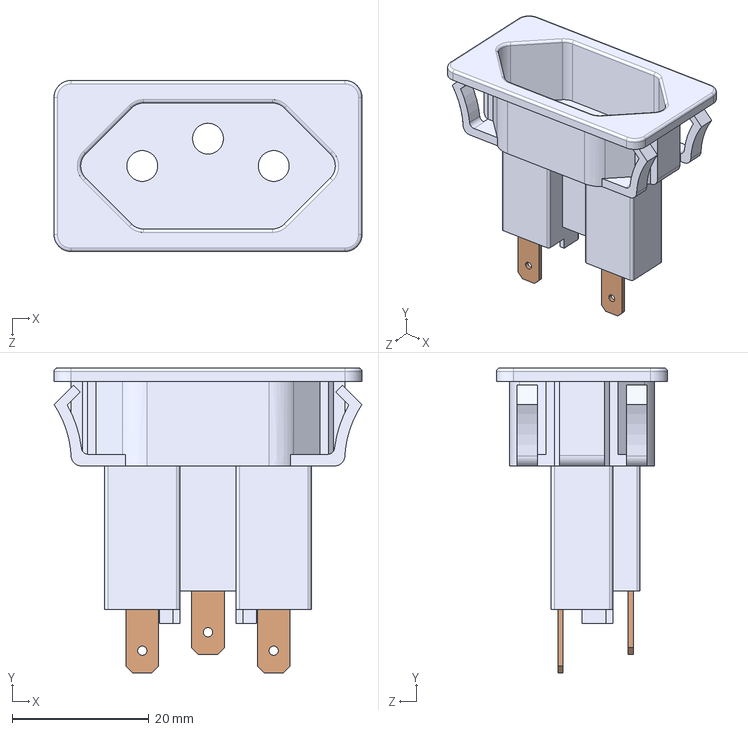
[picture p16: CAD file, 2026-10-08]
mechanical/models/tomada-tpa2-3-e3f.igs
45.0 x 44.6 x 25.0 mm

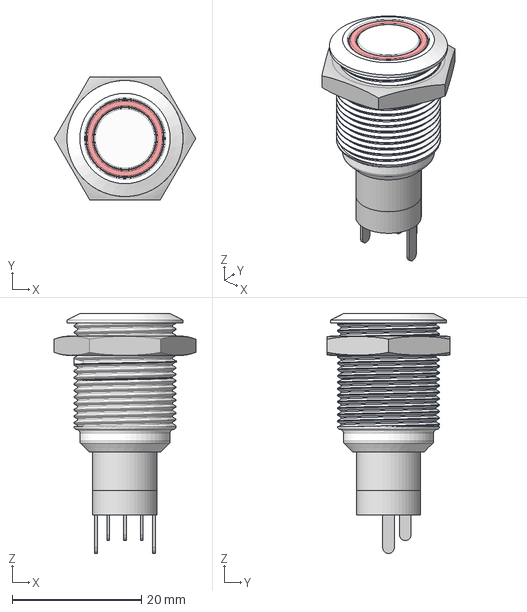
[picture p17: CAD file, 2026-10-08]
mechanical/models/adafruit-916-botao-metal-16mm.step
21.9 x 19.0 x 37.2 mm

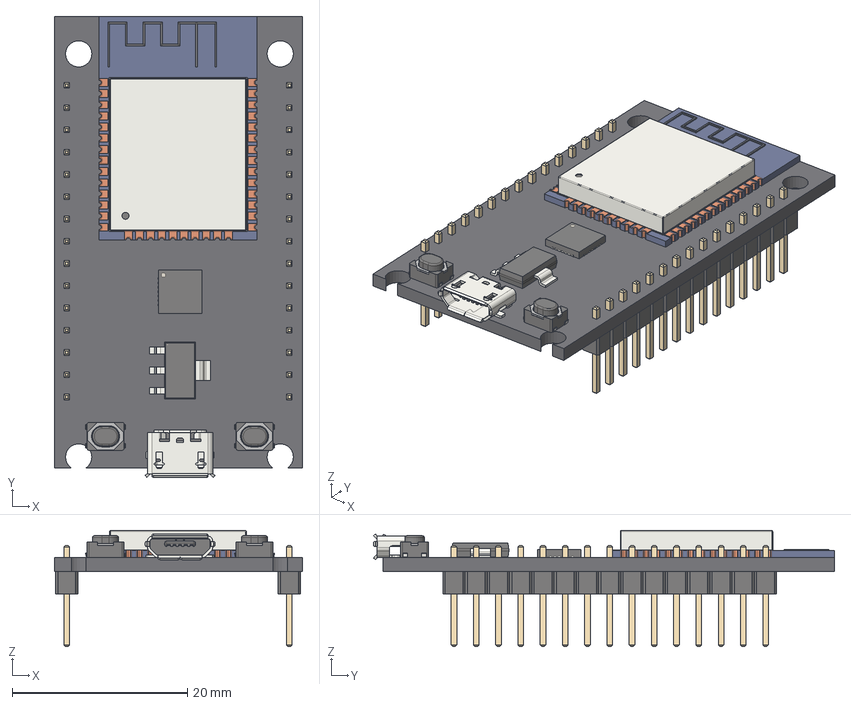
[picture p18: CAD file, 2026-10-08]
mechanical/models/esp32-devkit-v1.step
28.3 x 52.6 x 13.2 mm
placa
ESP32-WROOM-32
pinos_esq
pinos_dir
micro_usb
botao_en
botao_boot
AMS1117
CP2102

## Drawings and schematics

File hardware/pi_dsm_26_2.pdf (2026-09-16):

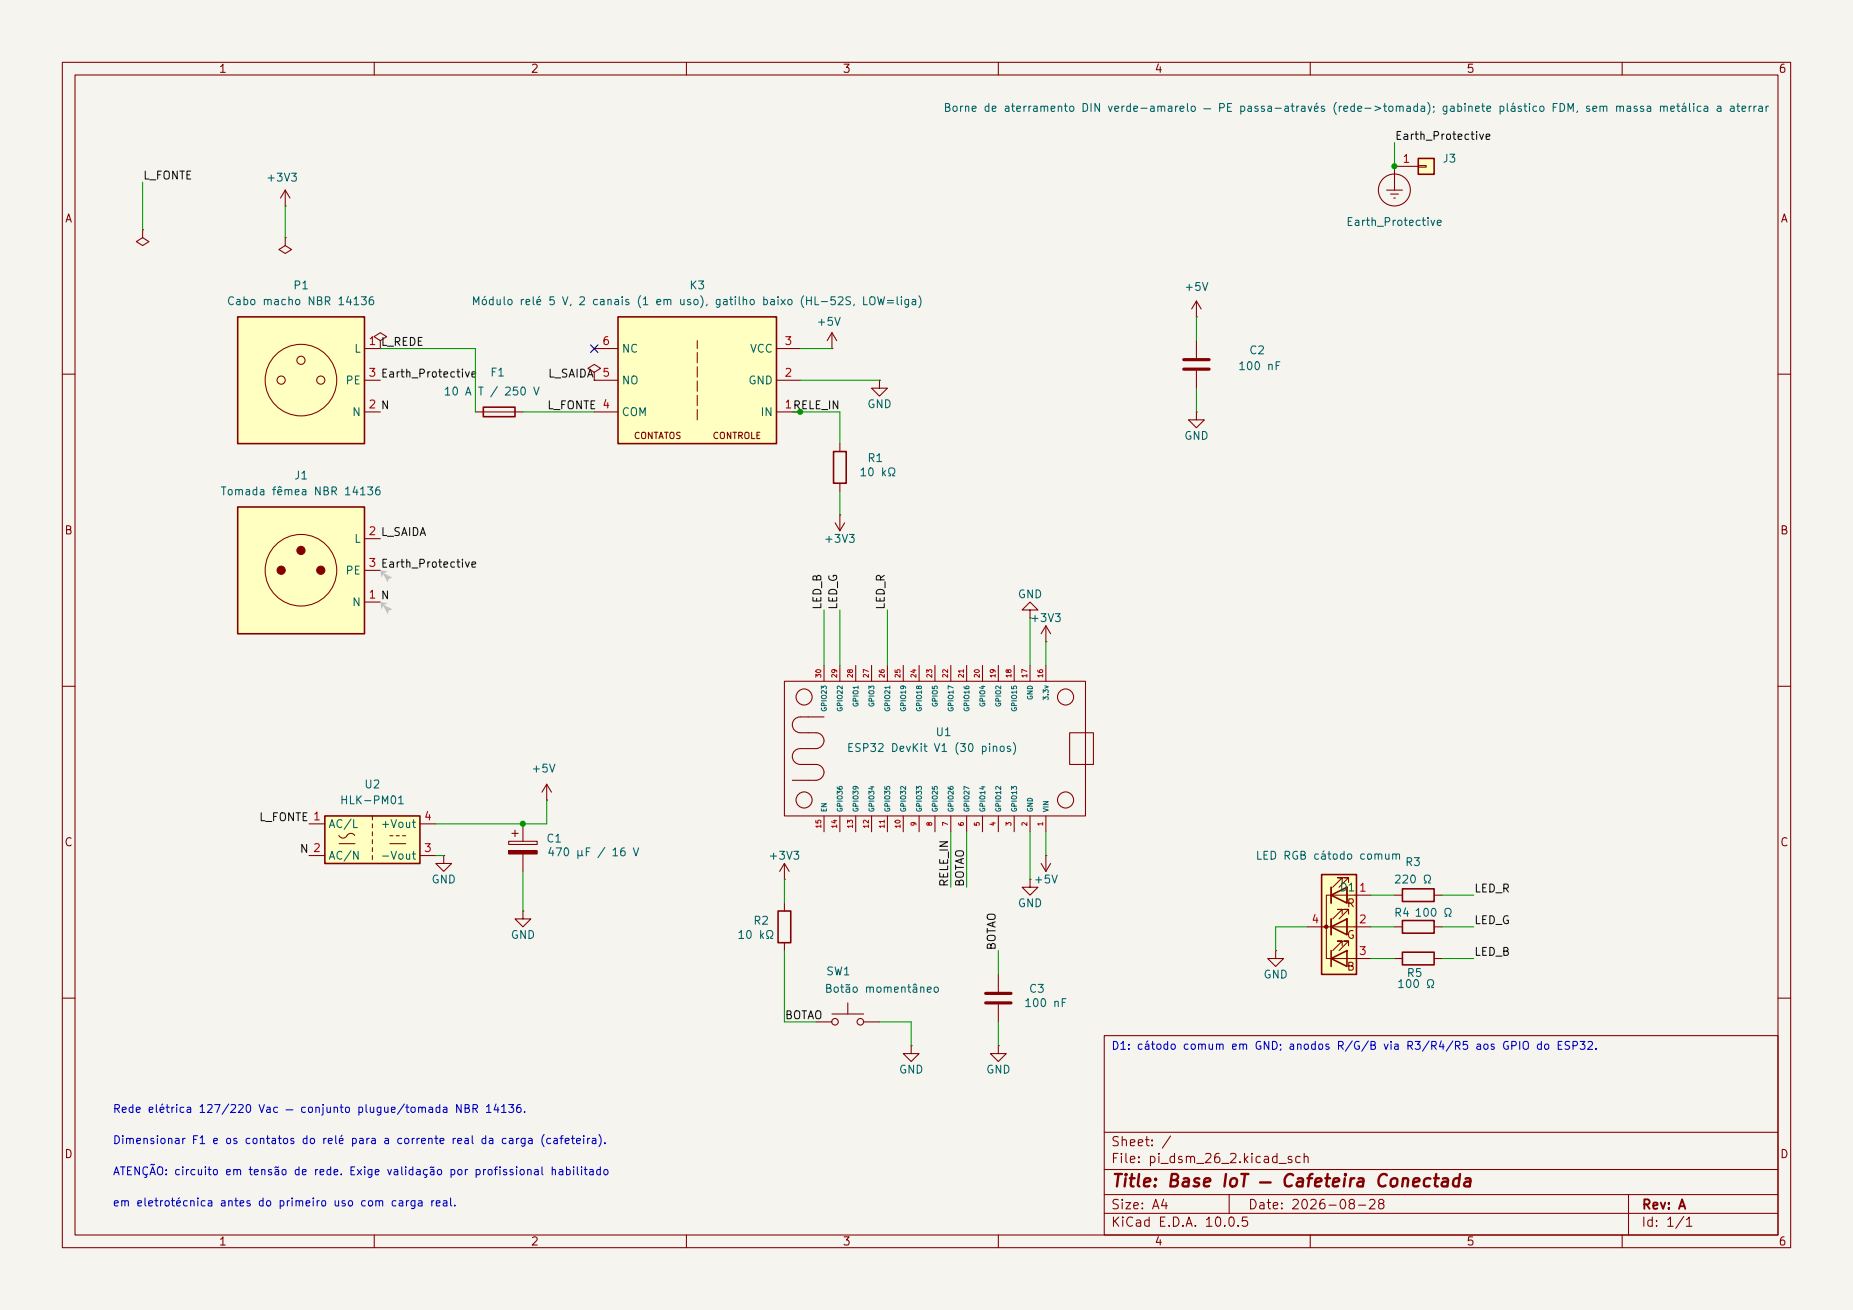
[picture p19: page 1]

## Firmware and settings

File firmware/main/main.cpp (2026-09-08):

/*
 * Cafey - Firmware do modulo IoT (ESP-IDF C++17)
 *
 * Estrutura de Active Objects sobre FreeRTOS (spec 5.2 / FW-02):
 * cada componente e uma task com fila propria e maquina de estados interna.
 * Sem memoria compartilhada — comunicacao so por eventos assincronos.
 *
 * Pinagem (conforme STATUS.md e esquematico KiCad):
 * - Rele (GPIO26): gatilho de nivel ALTO, R1 pull-down 10k externo
 * - Botao (GPIO27): pull-up externo R2 10k + C3 100nF, solto=1, pressionado=0
 * - LED RGB: catodo comum (R=21, G=22, B=23)
 */

#include "esp_log.h"
#include "core/ntp_sync.hpp"
#include "core/wifi_manager.hpp"
#include "storage/schedule_store.hpp"
#include "storage/event_queue_store.hpp"

#include "app/agendador.hpp"
#include "app/ble_event_proxy.hpp"
#include "app/ble_service.hpp"
#include "app/cafeteira.hpp"
#include "app/conectividade.hpp"
#include "core/esp_nimble_server.hpp"

namespace {
const char* TAG = "cafey";
}

// AOs com duracao de armazenamento estatica: vivem por toda a execucao.
cafey::app::Cafeteira g_cafeteira;
cafey::app::Conectividade g_conectividade;
cafey::app::Agendador g_agendador;

extern "C" void app_main(void) {
    ESP_LOGI(TAG, "boot - Cafey IoT (Active Objects)");

    // Carrega agendamentos e fila de eventos persistidos em NVS (spec §5.4):
    // sobrevivem a reboot e queda de energia. Consumidos futuramente pelos
    // Active Objects Agendador e Conectividade.
    static cafey::storage::ScheduleStore schedule_store;
    esp_err_t err = schedule_store.init();
    if (err != ESP_OK) {
        ESP_LOGE(TAG, "Falha ao carregar agendamentos de NVS: %d", err);
    } else {
        ESP_LOGI(TAG, "agendamentos carregados de NVS: %d", static_cast<int>(schedule_store.count()));
    }

    static cafey::storage::EventQueueStore event_queue_store;
    err = event_queue_store.init();
    if (err != ESP_OK) {
        ESP_LOGE(TAG, "Falha ao carregar fila de eventos de NVS: %d", err);
    } else {
        ESP_LOGI(TAG, "eventos pendentes carregados de NVS: %d", static_cast<int>(event_queue_store.size()));
    }

    // Inicializa Wi-Fi (STA) com reconexao automatica em backoff e credenciais
    // de provisionamento persistidas em NVS (UC-04). Sem credenciais gravadas,
    // fica aguardando o app/BLE provisionar via WifiManager::provision().
    static cafey::core::WifiManager wifi_manager;
    esp_err_t wifi_err = wifi_manager.init();
    if (wifi_err != ESP_OK) {
        ESP_LOGE(TAG, "Falha ao inicializar Wi-Fi: %d", wifi_err);
    }

    // Disparo do agendamento: o Agendador aciona o preparo pelo relogio interno
    // (spec §5.5), postando StartBrew para a Cafeteira, sem passar pela nuvem.
    g_agendador.set_on_fire([] {
        g_cafeteira.post(cafey::core::Message{cafey::core::MessageType::StartBrew, 0});
    });

    // Carrega os agendamentos persistidos para o Agendador executar offline.
    {
        static cafey::storage::Schedule loaded[cafey::storage::ScheduleStore::kMaxSchedules];
        const size_t n = schedule_store.count();
        for (size_t i = 0; i < n; ++i) loaded[i] = schedule_store.at(i);
        g_agendador.set_schedules(loaded, n);
    }

    // SNTP em background: ao sincronizar, o Agendador passa a disparar por horario.
    static cafey::core::NtpSync ntp_sync([] {
        g_agendador.post(cafey::core::Message{cafey::core::MessageType::TimeSynced, 0});
    });

    // Servico BLE (FW-17, spec §6.4): comando/estado/agendamentos delegam para
    // os mesmos handlers de dominio do caminho MQTT — sem regra de negocio na
    // camada BLE. E o proxy da fila de eventos pendentes (FW-18, spec §6.5).
    static cafey::core::EspNimbleServer ble_server(cafey::app::BleService::kServiceUuid);
    static cafey::app::BleService ble_service(
        ble_server,
        [](const cafey::app::CoffeeCommand& cmd) {
            using cafey::core::Message;
            using cafey::core::MessageType;
            switch (cmd.action) {
                case cafey::app::CoffeeAction::Ligar:
                    g_cafeteira.post(Message{MessageType::StartBrew,
                                             static_cast<int32_t>(cmd.duracao_s)});
                    break;
                case cafey::app::CoffeeAction::Desligar:
                case cafey::app::CoffeeAction::Cancelar:
                    g_cafeteira.post(Message{MessageType::StopBrew, 0});
                    break;
                case cafey::app::CoffeeAction::Unknown:
                    break;
            }
        },
        [](const cafey::storage::Schedule* list, size_t count,
           const cafey::app::SchedulePayloadMeta&) {
            // Mesmo caminho logico do downlink `agendamentos`: persiste e
            // recarrega o Agendador com a lista completa (idempotente).
            schedule_store.replace_all(list, count);
            g_agendador.set_schedules(list, count);
        });
    static cafey::app::BleEventProxy ble_event_proxy(ble_server, event_queue_store);

    if (ble_service.begin("cafey")) {
        ble_event_proxy.begin();
        ESP_LOGI(TAG, "servico BLE ativo (comando/estado/agendamentos + proxy de eventos)");
    } else {
        ESP_LOGE(TAG, "falha ao iniciar o servico BLE");
    }

    g_cafeteira.start();
    g_conectividade.start();
    g_agendador.start();
    ntp_sync.start();

    ESP_LOGI(TAG, "pronto - AOs Cafeteira/Conectividade/Agendador iniciados");
}

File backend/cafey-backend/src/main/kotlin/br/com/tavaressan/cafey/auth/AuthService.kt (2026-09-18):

package br.com.tavaressan.cafey.auth

import br.com.tavaressan.cafey.exception.BadCredentialsException
import br.com.tavaressan.cafey.mail.EmailSenderService
import br.com.tavaressan.cafey.security.JwtTokenService
import br.com.tavaressan.cafey.security.PasswordResetToken
import br.com.tavaressan.cafey.security.PasswordResetTokenRepository
import br.com.tavaressan.cafey.security.RefreshToken
import br.com.tavaressan.cafey.security.RefreshTokenRepository
import br.com.tavaressan.cafey.user.Usuario
import br.com.tavaressan.cafey.user.UsuarioRepository
import org.slf4j.LoggerFactory
import org.springframework.security.crypto.password.PasswordEncoder
import org.springframework.stereotype.Service
import org.springframework.transaction.annotation.Transactional
import java.time.Instant
import java.time.temporal.ChronoUnit
import java.util.UUID

@Service
class AuthService(
    private val usuarioRepository: UsuarioRepository,
    private val refreshTokenRepository: RefreshTokenRepository,
    private val passwordResetTokenRepository: PasswordResetTokenRepository,
    private val passwordEncoder: PasswordEncoder,
    private val jwtTokenService: JwtTokenService,
    private val emailSenderService: EmailSenderService
) {

    private val logger = LoggerFactory.getLogger(AuthService::class.java)

    @Transactional
    fun registrar(request: RegisterRequest): AuthResponse {
        val normalizedEmail = request.email.trim().lowercase()
        if (usuarioRepository.existsByEmail(normalizedEmail)) {
            throw BadCredentialsException("Email já cadastrado")
        }

        val usuario = Usuario(
            nome = request.nome.trim(),
            email = normalizedEmail,
            senhaHash = passwordEncoder.encode(request.senha)!!
        )
        val savedUser = usuarioRepository.save(usuario)

        return createAuthResponse(savedUser, UUID.randomUUID())
    }

    @Transactional
    fun login(request: LoginRequest): AuthResponse {
        val normalizedEmail = request.email.trim().lowercase()
        val usuario = usuarioRepository.findByEmail(normalizedEmail)
            ?: throw BadCredentialsException("Email ou senha inválidos")

        if (!passwordEncoder.matches(request.senha, usuario.senhaHash)) {
            throw BadCredentialsException("Email ou senha inválidos")
        }

        return createAuthResponse(usuario, UUID.randomUUID())
    }

    @Transactional
    fun refresh(request: RefreshRequest): AuthResponse {
        val rawToken = request.refreshToken.trim()
        val tokenHash = jwtTokenService.hashToken(rawToken)

        val tokenEntity = refreshTokenRepository.findByTokenHash(tokenHash)
            ?: throw BadCredentialsException("Token inválido ou expirado")

        if (tokenEntity.revogado) {
            // Detecção de reuso: token já revogado foi apresentado novamente -> revoga família inteira
            refreshTokenRepository.revokeFamily(tokenEntity.familiaId)
            throw BadCredentialsException("Token revogado. Reuso detectado, todas as sessões da família foram invalidadas.")
        }

        if (tokenEntity.expiraEm.isBefore(Instant.now())) {
            tokenEntity.revogado = true
            refreshTokenRepository.save(tokenEntity)
            throw BadCredentialsException("Token expirado")
        }

        // Rotação: revoga o token atual e gera um novo mantendo o mesmo familia_id
        tokenEntity.revogado = true
        refreshTokenRepository.save(tokenEntity)

        return createAuthResponse(tokenEntity.usuario, tokenEntity.familiaId)
    }

    private fun createAuthResponse(usuario: Usuario, familiaId: UUID): AuthResponse {
        val accessToken = jwtTokenService.generateAccessToken(usuario.id!!, usuario.email)
        val rawRefreshToken = jwtTokenService.generateRefreshToken()
        val tokenHash = jwtTokenService.hashToken(rawRefreshToken)

        val refreshToken = RefreshToken(
            usuario = usuario,
            tokenHash = tokenHash,
            familiaId = familiaId,
            expiraEm = Instant.now().plus(7, ChronoUnit.DAYS)
        )
        refreshTokenRepository.save(refreshToken)

        return AuthResponse(
            accessToken = accessToken,
            refreshToken = rawRefreshToken
        )
    }

    @Transactional
    fun solicitarRecuperacaoSenha(request: SolicitarRecuperacaoSenhaRequest): RecuperacaoSenhaResponse {
        val mensagemGenerica = "Se o email estiver cadastrado, as instruções foram enviadas."
        val normalizedEmail = request.email.trim().lowercase()
        val usuario = usuarioRepository.findByEmail(normalizedEmail)
            ?: return RecuperacaoSenhaResponse(mensagemGenerica)

        val rawToken = UUID.randomUUID().toString().replace("-", "")
        val tokenHash = jwtTokenService.hashToken(rawToken)

        val resetToken = PasswordResetToken(
            usuario = usuario,
            tokenHash = tokenHash,
            expiraEm = Instant.now().plus(1, ChronoUnit.HOURS)
        )
        passwordResetTokenRepository.save(resetToken)

        // O token só é entregue por e-mail — nunca na resposta da API (correção do achado de
        // segurança levantado na issue #105: sem isso, o endpoint público era um account takeover).
        // Falha de envio é apenas logada: não pode virar 5xx nem alterar a resposta, senão vira
        // oráculo de enumeração de contas.
        try {
            emailSenderService.enviarEmailRecuperacaoSenha(normalizedEmail, rawToken)
        } catch (ex: Exception) {
            logger.error("Falha ao enviar e-mail de recuperação de senha para {}", normalizedEmail, ex)
        }

        return RecuperacaoSenhaResponse(mensagem = mensagemGenerica)
    }

    @Transactional
    fun redefinirSenha(request: RedefinirSenhaRequest) {
        val tokenHash = jwtTokenService.hashToken(request.token.trim())
        val resetToken = passwordResetTokenRepository.findByTokenHash(tokenHash)
            ?: throw BadCredentialsException("Token de recuperação inválido ou expirado")

        if (resetToken.utilizado || resetToken.expiraEm.isBefore(Instant.now())) {
            throw BadCredentialsException("Token de recuperação inválido ou expirado")
        }

        val usuario = resetToken.usuario
        usuario.senhaHash = passwordEncoder.encode(request.novaSenha)!!
        usuario.atualizadoEm = Instant.now()
        usuarioRepository.save(usuario)

        resetToken.utilizado = true
        passwordResetTokenRepository.save(resetToken)
    }
}

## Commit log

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2026-08-28 Corrige conexões do esquemático conforme especificação de componentes
    Reescreve hardware/pi_dsm_26_2.kicad_sch com a pinagem e as ligações da
    especificação de componentes:
    - J1/J2 -> Conn_01x03, PS1 -> Conn_01x04; K1b1 mantido (ref "K1b" é
    inválida no KiCad, precisa terminar em dígito)
    - R_US -> R, adiciona R5; valores: R1/R2 10k, R3 220R, R4/R5 100R,
    C1 470uF/16V, C2/C4 100nF, F1 10A/250V
    - Fecha ligações que faltavam: fase chaveada K1b1(NO) -> J2 -> cafeteira,
    resistores de série de cada cor do LED RGB (D1 cátodo comum),
    R1 de RELE_IN a GND, GND do pino 17 do ESP32
    - VIN e 3V3 do símbolo esp32_30pin passam a power_in para não colidir
    com os PWR_FLAG de +5V/+3V3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
    [pi_dsm_26_2.kicad_sch]
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2026-08-31 Revisa esquematico: simbolos dedicados, terra da chapa e correcoes
    - PS1->U2 (Converter_ACDC:HLK-PM01), plugue/tomada como
    Conn_Plug/Receptacle_3P_Protected (P1/J1), rele num simbolo unico
    relay_module:Relay_Module_1CH (K3, biblioteca do projeto)
    - Restaura J3 (terminal olhal) + simbolo Earth_Protective no no de terra
    da chapa de aco; rede PE renomeada para Earth_Protective (P1.PE, J1.PE, J3)
    - Corrige fiacao do plugue de entrada (fase/neutro/terra estavam trocados);
    PWR_FLAG em L_REDE e L_SAIDA
    - Preenche campos de Valor de P1, J1 e K3; fecha buraco de numeracao C4->C3
    - Netlist conferida no a no com kicad-cli; ERC limpo salvo GPIOs livres do
    U1 e duas exclusoes documentadas (pass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
    [pi_dsm_26_2.kicad_sch]
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2026-09-02 feat(mechanical): modelo paramétrico da Peça 1 do pedestal no FreeCAD
    Peça 1 (peça dobrada) de docs/status-modulo-fisico.md como sólido Part
    paramétrico, 100% por script headless (FreeCAD 1.1.3), dirigido pelo
    Spreadsheet `params`. Sem o addon SheetMetal: planificação analítica
    (BD = 2·setback − BA), auditável e independente do unfolder.
    - params/parametros.csv → Spreadsheet params (placeholders arbitrados que
    o revisor da empresa corrige; geometria depende deles por expressão)
    - build_peca1.py: tampo + 4 saias + 4 abas de fundo + 4 abas de canto,
    alívios de canto, furação e todas as aberturas por face. Cada objeto
    carrega Label + Label2 descritivo; objeto notas_fab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
    [parametros.csv]
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2026-09-02 fix(mechanical): rasgo de ventilação invadindo o furo de canto na saia esquerda
    rasgo_e_4 (centro em Y=185, borda em Y=197,5) se sobrepunha ao furo de canto
    inferior fix_et_lo (Y≈198,8) — 1,2 mm³ de interseção. A grade de rasgos usava
    o centro na margem de extremidade (25 mm), deixando metade do rasgo (12,5 mm)
    dentro da zona das abas de canto, violando a regra do documento ("≥ 25 mm das
    extremidades").
    - build_peca1.py: grade recuada de rasgo_l/2 além da margem, para que a BORDA
    do rasgo respeite os 25 mm. Novos centros: 37,5 / 71,25 / 105 / 138,75 / 172,5
    - check_peca1.py: valida que todo rasgo fica em Y ∈ [me, pegada_y − me] e que
    não há sobreposição 3D real entre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
2026-09-02 fix(mechanical): aberturas traseiras não vazavam a chapa
    prensa_cabo e tomada_j1 usavam base em Y = pegada_y − 1 e altura espessura + 2,
    cobrindo só Y [209, 210] da saia traseira (Y [208,8, 210]). Sobrava ~0,2 mm de
    pele na face interna e o corte não alcançava a face externa inteira — a abertura
    ficava "tapada por chapa". A entrada de energia do módulo (prensa-cabo) e a
    tomada J1 não estavam realmente abertas.
    - build_peca1.py: base das aberturas traseiras em Y = pegada_y − espessura − 1
    (antes da face interna), mesma lógica das aberturas frontais
    - check_peca1.py: sonda no centro de cada abertura de face confirmando que
    atravessa toda a chapa (janela_rf, furo_led, furo_b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
2026-09-02 chore(mechanical): validação de conjunto e export STEP da Peça 2
    - check_montagem.py: valida o que só aparece com as duas peças juntas —
    não-interferência, contato fundo/abas, pilha do parafuso (fundo_furo → aba →
    porca-rebite com material em volta para a porca cravar), cobertura das 4 abas
    pelo fundo, elevação total
    - build_peca2.py: exporta peca2.step (estava documentado mas não era gerado)
    - README: check_montagem na sequência; nota da elevação
    Verificação completa: 10 scripts passam; peca1/peca2/montagem STEP são sólidos
    válidos e fechados; elevação 56,2 mm (61,2 com apoio máx — 1,2 acima dos 60 do
    documento, que precede a decisão do fundo por baixo).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
2026-09-02 feat(firmware): esqueleto ESP-IDF C++17 e driver do rele com gatilho alto (#110)
    * feat(firmware): esqueleto ESP-IDF C++17 e driver do rele com gatilho alto (#21, #23)
    * fix(firmware): remove non-existent core include directory and update sdkconfig CPU freq keys
    * fix(firmware): configure 4MB flash size for ESP32 DevKit V1
    * fix(firmware): set C++17 via sdkconfig Kconfig and remove CMAKE_CXX_EXTENSIONS restriction
    [partitions.csv]
2026-09-02 fix(mechanical): respiros da lateral direita não vazavam a chapa
    rasgo_d_0..4 usavam base X = pegada_x − 1 e largura espessura + 2, cobrindo só
    X [259, 260] da saia direita (X [258,8, 260]). Sobrava 0,2 mm de pele na face
    interna — os 5 respiros da direita apareciam tapados no .step. Os da esquerda
    (base X = −1) já estavam certos.
    - build_peca1.py: base X dos rasgo_d em pegada_x − espessura − 1 (antes da face
    interna), mesma lógica dos rasgo_e e das aberturas frontais/traseiras
    - check_peca1.py: a sonda de "atravessa a chapa" passa a cobrir também todos os
    rasgo_e/rasgo_d (antes só as aberturas maiores)
    peca1.step: sólido válido e fechado; os 9 respiros vazam (resto 0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
2026-09-04 feat(firmware): persistência em NVS de agendamentos e fila de eventos (FW-06) (#112)
    * feat(firmware): mutex-protected NVS blob store (FW-06)
    Adiciona cafey::core::Mutex/LockGuard (FreeRTOS no ESP32, std::mutex no
    host) e cafey::storage::NvsStore, wrapper RAII sobre a API de NVS do
    ESP-IDF com acesso serializado por mutex, conforme spec §5.4. Inclui
    mock_esp_nvs.hpp para permitir testes de unidade fora do toolchain
    ESP-IDF, no mesmo padrao de mock_esp_gpio.hpp.
    * feat(firmware): persistencia de agendamentos e fila de eventos em NVS (FW-06)
    Adiciona ScheduleStore (lista de agendamentos, capacidade fixa 16) e
    EventQueueStore (fila circular de eventos de preparo, capacidade fixa
    32), ambos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
    [main.cpp]
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2026-09-04 fix(firmware): reposiciona fios do diagrama Wokwi sobrepostos visualmente
    Apenas ajuste de roteamento visual no diagram.json — mesmos componentes
    e conexões, sem mudança de circuito.
2026-09-04 fix(firmware): compat com ESP-IDF v6.1 (esp_driver_gpio, esp_timer_create_args_t)
    Encontrado ao rodar idf.py build de verdade localmente (v6.1), fora do
    fallback de testes de host usado até então (Docker indisponível):
    - main/CMakeLists.txt: driver/gpio.h foi desmembrado para o componente
    esp_driver_gpio no v6.1 (v5.3, usado pelo CI, ainda o embutia via
    driver). Adiciona esp_driver_gpio ao REQUIRES.
    - wifi_manager.cpp: esp_timer_create_args_t ganhou o campo
    skip_unhandled_events no v6.1, quebrando o inicializador designado
    parcial sob -Werror=missing-field-initializers. Troca para zero-init
    + atribuição por campo, robusto a novos campos em qualquer versão.
2026-09-04 docs(firmware): documenta ativação do ESP-IDF local e gotchas de indisponibilidade
    Registra os problemas encontrados ao destravar o idf.py nesta máquina:
    source não persiste entre shells separados, instalação com venv Python
    incompleto, e divergência de versão local (v6.1) vs. CI (v5.3) como
    fonte de falso-negativo/positivo.
2026-09-08 fix(firmware): rele active-low (HL-52S) e correções de wiring do diagram.json
    - relay.cpp: inverte a lógica de Relay::set()/init() para active-low
    (nível BAIXO energiza), conforme o módulo físico disponível para o
    teste de bancada é o HL-52S. R1 deixa de ser pull-down e passa a
    pull-up externo no esquemático (ver diagram.json), evitando falso
    positivo de energização durante boot/reset/brownout.
    - diagram.json: remove o pino GND.3 inválido (wokwi-esp32-devkit-v1 só
    tem GND.1/GND.2) e o part C3 (tipo wokwi-capacitor não reconhecido
    pelo motor de simulação atual) — bugs pré-existentes encontrados ao
    rodar wokwi-cli lint, não relacionados às mudanças de active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
    [relay.cpp]
2026-09-08 fix(firmware): simulação Wokwi headless (wokwi-cli) sem saída serial (#117)
    * fix(firmware): conecta $serialMonitor no diagram.json para simulação headless funcionar (FW-Wokwi)
    Causa raiz de #115 encontrada por bissecção: wokwi-cli conecta e roda
    a simulação normalmente (inclusive o firmware real), mas sem uma
    conexão explícita esp:TX0/RX0 -> $serialMonitor:RX/TX no diagram.json,
    nenhum byte de serial chega ao CLI — nem o banner de boot do ROM, que
    independe do firmware. Silencioso, sem erro, sem timeout diferenciado.
    Confirmado por eliminação: testado com nosso e o elf oficial de
    smoke-test (wokwi/esp32-test-binaries), com e sem os bugs de wiring já
    corrigidos, com wokwi-e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
    [relay.cpp]
2026-09-08 feat(mechanical): reformula pedestal para impressao 3D (FDM) (#118)
    Substitui a Peca 1 dobrada (8 dobras + 4 abas de canto) por um solido
    unico impresso (tampo + 4 paredes + flange continua), com parede de
    2,4 mm (minimo FDM estrutural) no lugar de 1,2 mm de chapa. Fixacao
    Peca1/Peca2 passa de porca-rebite para insert termico M3. Recria 1:1
    o catalogo de aberturas/ventilacao e preserva o arranjo interno de
    14 componentes e a separacao rede/baixa tensao. Adiciona export STL e
    uma estimativa analitica de flecha do tampo sob a carga de operacao.
    Pipeline em chapa dobrada (build_peca1.py etc.) preservado intacto como
    historico de decisao - nao foi alterado.
    Refs #116
    [componentes_3d.csv, parametros_3d.csv]
2026-09-08 docs(firmware): corrige tabela de pinagem e descrição do driver (active-low)
    Resíduos do active-high que passaram despercebidos nas PRs anteriores
    (#117 só tocou a seção de Wokwi do README).
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2026-09-08 feat(firmware): preparo local, LED RGB e evento_id (FW-07/05/08) (#120)
    * feat(firmware): temporizador local de preparo aplicando duracaoS (FW-07)
    O Active Object Cafeteira passa a contar duracaoS pelo tick local e encerrar
    o preparo com resultado CONCLUIDO; corte por botao/comando resulta CANCELADO.
    * feat(firmware): driver do LED RGB indicando estado e problema de rede (FW-05)
    Cor reflete o estado da cafeteira e o piscar sinaliza problema de rede,
    conforme spec §5.3; inclui testes de host.
    * feat(firmware): gerador de evento_id no formato bootId:seq (FW-08)
    seq monotonico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
    [rgb_led.cpp]
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2026-09-08 feat(firmware): MQTT/TLS AWS IoT, tópicos e fila de eventos (FW-10/11/12/16) (#122)
    * feat(firmware): cliente MQTT sobre TLS com X.509 para AWS IoT Core (FW-10)
    Adiciona IMqttClient (abstracao testavel), MqttTopics, EspMqttClient sobre
    esp-mqtt e MqttConfigStore para carregar broker/certificados de NVS sem
    embutir credenciais no binario. QoS 1 em todas as operacoes (spec §6.1).
    * feat(firmware): assinar comando e agendamentos pelo nome exato (FW-11)
    DownlinkSubscriber assina os topicos descendentes completos em QoS 1, sem
    wildcard: o AWS IoT Core nao entrega mensagem retida a filtro com '+'/'#'
    (spec-backend §6.3), e agendamentos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
2026-09-08 feat(firmware): versão monotônica de agendamentos e horário provisório sem NTP (FW-13/15) (#124)
    * feat(firmware): regra de versão monotônica para lista de agendamentos (FW-13)
    ScheduleStore::replace_all_if_newer persiste a `versao` recebida no MQTT
    `agendamentos` junto da lista e ignora payloads com versão menor ou igual
    à gravada em NVS, protegendo contra o retain antigo reentregue na
    reconexão (spec-backend §6.2).
    * feat(firmware): marca horário provisório em preparo antes do sync NTP (FW-15)
    Quando o preparo termina antes da sincronização NTP o relógio interno não
    é confiável: Event.horario_provisorio carimba e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
2026-09-08 Revisão de compras: correções de hardware, mecânico e lista consolidada (#128)
    * fix(hardware): relé active-low, R1 pull-up e F1 10 A T
    Alinha o esquemático com o firmware e o módulo de relé real (HL-52S,
    2 canais, gatilho de nível BAIXO):
    - K3: "1 canal, gatilho alto" -> "2 canais (1 em uso), gatilho baixo"
    - R1 passa de pull-down (GND) para pull-up (+3V3): com o GPIO em alta
    impedância no boot, IN fica em ALTO = relé desligado (estado seguro)
    - F1: "10 A / 250 V" -> "10 A T / 250 V" (retardado; protege a carga e
    o contato do relé, decisão de manter a filosofia do esquemático)
    - J3: valor atualizado para borne de aterramento DIN (gabinete plástico
    FDM, sem massa metá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
    [componentes_3d.csv, parametros_3d.csv, pi_dsm_26_2.kicad_sch]
2026-09-08 fix(firmware): migração de layout NVS com prefixo de schema (FW-19) (#129)
    * fix(firmware): migração de layout NVS com prefixo de schema (FW-19)
    Adiciona magic + schema_version no início dos PersistedLayout de ScheduleStore
    e EventQueueStore. init() passa a detectar blob de layout antigo, magic/schema
    desconhecido ou tamanho incompatível e tratar como store vazio (recuperável via
    republish retido), em vez de propagar ESP_ERR_INVALID_SIZE e descartar os dados
    silenciosamente. EventQueueStore migra o layout legado conhecido (pré-#124),
    carimbando horario_provisorio=false e regravando no layout novo, para não perder
    eventos de preparo ainda não publicados. Novo helper NvsStore::blob_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
2026-09-09 refactor(backend): padroniza coordenada Maven e pacote para br.com.tavaressan.cafey (#135)
    Corrige a divergencia entre pasta e package identificada na issue #132: o
    group do Gradle e todos os `package`/`import` de main e test passam de
    br.com.cafey para br.com.tavaressan.cafey, e a pasta de testes e movida
    (git mv) para o mesmo namespace ja usado pelas fontes de main.
    Claude-Session: https://claude.ai/code/session_01Vt8ZFdDCcpU6rC7hAeTvXz
    [AuthService.kt]
2026-09-09 fix(backend): desativa Open Session In View e valida queries JPA (BE-26) (#138)
    Desliga spring.jpa.open-in-view em producao e testes para evitar lazy
    loading nao rastreado fora das transacoes de servico. As associacoes
    LAZY das entidades ja eram resolvidas via JOIN FETCH ou DTO mapping
    dentro dos metodos @Transactional (nenhuma query nova foi necessaria).
    Adiciona OpenInViewIntegrationTest, um teste de integracao ponta a
    ponta (MockMvc real + H2 real, sem mocks de repositorio) que exercita
    os endpoints de listagem de dispositivos, agendamentos e
    compartilhamentos pela camada HTTP - o unico jeito de expor uma
    LazyInitializationException que so ocorreria na serializacao da
    resposta, fora da t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
2026-09-09 fix(backend): hardening pós-review de chaves RSA e rate limiter (#104, #106) (#139)
    * fix(backend): falha o boot em prod sem chaves RSA externas (#104)
    O fallback de chave RSA efêmera era usado silenciosamente em qualquer
    perfil, inclusive produção — um deploy que esquecesse
    CAFEY_JWT_PRIVATE_KEY/CAFEY_JWT_PUBLIC_KEY subiria normalmente e
    invalidaria todos os tokens a cada restart. O critério de aceite da
    issue #104 restringe o fallback a perfil local/testes; agora o boot
    falha com IllegalStateException quando o perfil ativo é "prod" e
    nenhuma chave externa foi configurada.
    Claude-Session: https://claude.ai/code/session_01Vt8ZFd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
2026-09-09 feat(backend): documentação OpenAPI 3 e Swagger UI via SpringDoc (#107) (#136)
    * build(backend): adiciona springdoc-openapi-starter-webmvc-ui 3.1.1
    Dependência necessária para expor /swagger-ui.html e /v3/api-docs (issue #107).
    * feat(backend): configura OpenAPI 3 com SecurityScheme Bearer JWT
    Adiciona bean OpenAPI com título/versão/descrição da API e libera as rotas
    do Swagger UI e do schema api-docs no SecurityConfig (BE-25).
    *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
    [SecurityConfig.kt]
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2026-09-11 feat(apps): URL do backend configurável por build + spike de distribuição Android (#153)
    * feat(apps): URL do backend Android configurável por build (APP-12) (#147)
    O app não alcançava o backend num aparelho físico: `AppContainer` aceitava
    `baseUrl` por parâmetro, mas `App()` nunca repassava, e o padrão Android
    (`10.0.2.2`) só existe para o emulador. Agora `App(baseUrl)` propaga a URL
    para `AppContainer`, e `androidApp` resolve `BACKEND_BASE_URL` via
    `BuildConfig`, lido de `-PbackendBaseUrl`, da env `BACKEND_BASE_URL` ou de
    `local.properties` — mantendo `10.0.2.2` como padrão sem configuração extra.
    O `network_security_config` de debug passa a ser gerado em build incluindo
    o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
2026-09-11 feat(infra): provisiona AWS IoT Core — things, certificados X.509 e políticas (device + backend) (#155)
    * feat(infra): template de politica IoT do dispositivo e provisionamento NVS (#123)
    Politica de minimo privilegio via ${iot:Connection.Thing.ThingName} (INFRA-05, issue #123) e template de CSV para gerar a particao NVS de credenciais MQTT/TLS via nvs_partition_gen.py, conforme mqtt_config_store. Chaves/certs reais ficam fora do versionamento (.gitignore).
    Claude-Session: https://claude.ai/code/session_01EJ95d4kQTeaNRjREhtqndC
    * feat(infra): perfil prod do backend com config AWS IoT via env (#123)
    application-prod.yml mapeia aw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
2026-09-11 feat(infra): deploy remoto do backend em Lightsail + CI/CD via GitHub Actions (#160)
    * feat(infra): adiciona Caddy + compose.prod.yaml para deploy remoto (INFRA-07)
    Serviço caddy faz reverse proxy com HTTPS automático (Let's Encrypt via
    HTTP-01) para o subdomínio DuckDNS, na frente do serviço app do compose
    da #149. compose.prod.yaml é um override aplicado só no deploy remoto,
    sem alterar o compose.yaml usado em desenvolvimento local.
    * feat(infra): deploy automático do backend via GitHub Actions (INFRA-07/#158)
    Workflow builda a imagem no runner do GitHu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
2026-09-11 feat(infra): adiciona Caddy + compose.prod.yaml para deploy remoto (INFRA-07) (#161)
    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
2026-09-11 feat(apps): URL do backend configurável por build no alvo Web (APP-14, #157) (#163)
    * feat(apps): URL do backend configurável por build no alvo Web (APP-14, #157)
    Substitui a constante fixa `http://localhos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
2026-09-11 ci(apps): deploy do webApp (Kotlin/Wasm) para Vercel via GitHub Actions (#164)
    * ci(apps): deploy do webApp (Kotlin/Wasm) para Vercel via GitHub Actions
    Build (Gradle + JDK) roda no runner do GitHub Actions e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
2026-09-14 feat(apps): tela de cadastro manual de dispositivo (APP-13) (#165)
    Conta nova não tinha como cadastrar uma cafeteira pelo app; a HomeScreen
    ficava sem dispositivo e sem caminho de recuperação. Adiciona
    DeviceRegisterScreen (cadastro manual, recorte mínimo desta issue —
    provisionamento BLE/Wi-Fi fica para depois de APP-11/firmware) e estado
    vazio explícito na HomeScreen com botão para cadastrar. Validação do
    nome em shared/domain/validation, espelhando CriarDispositivoRequest do
    backend.
    Closes #148
    Claude-Session: https://claude.ai/code/session_012tsjdmeyLtTswJD3hGEc8P
2026-09-14 feat(apps): gráfico de distribuição por origem no histórico (APP-10, #69) (#166)
    * feat(app): adiciona gráfico de distribuição por origem no histórico (APP-10)
    Substitui o resumo textual "origem: tota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
2026-09-14 test(apps): pin paridade de largura do Desktop com o Web (APP-09, #68) (#167)
    * test(apps): pin paridade de largura do Desktop com o Web (#68)
    O cliente Desktop ja reaproveitava integralmente o `shared` (App(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
2026-09-14 feat(apps): cliente BLE de fallback de comando e proxy de eventos (APP-11, #70) (#168)
    * feat(apps): cliente BLE de fallback de comando e proxy de eventos (APP-11)
    Implementa o fluxo de spec §6.4/§6.5: BleC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
2026-09-14 feat(infra): ativa integração AWS IoT Core em produção (INFRA-05, #123) (#174)
    Workflow builda a imagem no runner do GitHub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
2026-09-14 ci(apps): integra webApp (Vercel) com backend (AWS Lightsail) em produção (#175)
    Build (Gradle + JDK) roda no runner do GitHub Actio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
2026-09-14 fix(apps): letterSpacing em .em ao invés de .sp na CafeyTypography (APP-15, #170) (#179)
    * fix: use .em (relative) instead of .sp (absolute) for letterSpacing in CafeyTypography
    Issue #170 — screenTitle, c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
2026-09-14 fix(apps): breakpoints responsivos e ícones da bottom bar (APP-16/APP-17, #172, #173) (#180)
    * fix: add responsive nav shell breakpoints (tabbar/rail/sidebar)
    Introduce BoxWithConstraints-driven NavShellSize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
2026-09-17 feat(apps,backend): cartão Próximo preparo e sequência de manhãs reais na Home (APP-18/APP-19, #176, #177) (#181)
    * fix(apps): restore executable bit on gradlew
    gradlew was checked in without the executab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
2026-09-18 chore(vetor): configura Vetor no projeto e gera Design Contracts do protótipo
    Inicializa .claude/vetor/ (config detectado + module-test-map preservado),
    ajusta .gitignore para versionar .claude/vetor/ e .claude/rules/ sem expor
    worktrees/scratch/skills locais, e gera os 5 Design Contracts em
    .vetor/design/handoff/ a partir do protótipo em docs/docs_interface/prototype/,
    corrigidos contra a implementação real em apps/ e backend/ (sincronizada com
    origin/main nesta sessão).
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2026-09-18 fix(backend): bloqueia /test/** sem autenticação em produção (#193)
    * fix(backend): bloqueia /test/** sem autenticação em produção (#185)
    TestController vivia em src/main sem nenhuma guarda de @Profile, e
    SecurityConfig liberava .permitAll() em /test/** para qualquer ambiente,
    incluindo produção, expondo endpoints que disparam exceptions arbitrárias
    sem autenticação.
    - TestController agora só é registrado fora do perfil prod (@Profile("!prod")).
    - SecurityConfig deixa de liberar /test/** quando o perfil ativo é prod,
    caindo em anyRequest().authenticated() (401 sem token).
    - Testes de integração cobrindo ambos os perfis (prod: 401; default: 500,
    comportamento preexiste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
    [SecurityConfig.kt]
2026-09-18 fix(backend): remove token de recuperação de senha da resposta da API (#195)
    * fix(backend): remove token de recuperação de senha da resposta da API (#105)
    O endpoint público /auth/recuperar-senha devolvia o token de reset em
    texto claro no corpo da resposta HTTP, permitindo account takeover sem
    autenticação para quem soubesse um e-mail cadastrado.
    Introduz a abstração EmailSenderService (BE-23) com LogEmailSenderService
    ativo em qualquer perfil != prod, que apenas registra o link de
    redefinição no log — sem SMTP/SES real. AuthService passa a entregar o
    token exclusivamente por esse canal; a resposta da API volta a conter só
    a mensagem genérica, em qualquer perfil.
    A implem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
    [AuthService.kt]
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2026-10-02 feat(backend): envio real de e-mail de recuperação via AWS SES (SMTP) em prod
    ## Resumo
    - `ProdEmailSenderService` (`@Profile("prod")`) envia o e-mail de recuperação via AWS SES por SMTP (`spring-boot-starter-mail` + `JavaMailSender`), com STARTTLS e timeouts de 5s.
    - Configuração SMTP (`CAFEY_MAIL_SMTP_HOST/PORT/USERNAME/PASSWORD`, remetente e URL de reset) via variáveis de ambiente, propagadas pelo `compose.prod.yaml`; nenhuma credencial commitada. Boot em prod sem as variáveis continua funcionando.
    - Página estática `redefinir-senha.html` servida pelo backend (B4), liberada no `SecurityConfig`; trata 400/401 como link inválido.
    - Docs de deploy atualizadas (`DEPLOY.md`, `README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
    [SecurityConfig.kt]
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

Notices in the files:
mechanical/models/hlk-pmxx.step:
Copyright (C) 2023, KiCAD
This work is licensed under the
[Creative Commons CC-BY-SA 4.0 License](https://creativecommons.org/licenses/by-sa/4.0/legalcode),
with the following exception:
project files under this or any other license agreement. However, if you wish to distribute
